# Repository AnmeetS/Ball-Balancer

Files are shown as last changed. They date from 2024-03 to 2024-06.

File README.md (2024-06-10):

<p align="center">project-image</p>

Hello and welcome to the GitHub repository of my Ball Balancing Robot! This project marks a significant milestone in my embdeded software engineering journey, combining my passion for robotics with hands-on learning and innovation. Below, I delve into the inspiration, process, challenges, and future plans for this project.

## Inspiration ✨

One of my most driving aspirations is to create a robot that can help people in their daily lives. This realization led me to discover my passion for robotics software development. Given the niche nature of this field and the lack of specific courses in school, I took it upon myself to explore the basics of robotics coding concepts over the past two months. This exploration began with working with PID algorithms, and it inspired me to create a ball balancing machine. The idea was to develop a project that could practically apply these concepts while also challenging my understanding and skills.

## The Process 🛠️

The project began with extensive research. I invested in stepper motors due to their high accuracy and quiet operation. The design needed a platform with at least two degrees of freedom (pitch and yaw) to angle the platform in any direction. Initially, I considered using a gimbal, but I encountered clearance issues with the motors. This led me to explore other manipulator designs, eventually settling on a 3-RPS parallel manipulator. A 3-RPS manipulator was ideal because it provided the necessary degrees of freedom, but I ultimately chose a varation of this manipulator (A 3-RRS manipulator platform) due to the lack of access to prismatic actuation.

Once the platform design was finalized, I attempted calculating the inverse kinematics necessary for coordinating platform tilt with stepper motor angles. This process involved advanced mathematical calculations, including solving complex equations related to the robot's geometry and movement using linear transformations. Each component—inverse kinematics values, resistive touchpad readings, motor control algorithms, and the PID control algorithm—was thoroughly tested. After a series of tests and refinements, I assembled and tuned the robot. The result is a finely tuned ball balancing machine, as demonstrated in the video below.

## Demo 🚀

[Watch the demo](https://www.anmeetsekhon.com/assets/videos/Ball%20Balancing%20Speed%20Up%20Video.mp4)

## Built with 💻

Technologies used in the project:

- Arduino
- C++
- Stepper Motors
- Solidworks

## Challenges I Ran Into 🚧

One of the biggest challenges was calculating the inverse kinematics. This complex calculation required a solid understanding of linear algebra and advanced mathematics. The process involved solving equations that define the relationship between the robot's physical structure and its movements. Specifically, it required deriving the mathematical model that translates the desired tilt of the platform into specific angles for the stepper motors. The complexity and precision required for these calculations pushed me to deepen my knowledge and skills in this area, making it one of the most challenging yet rewarding aspects of the project.

For those interested, a portion of the calculations performed for the inverse kinematics can be found [here](https://github.com/AnmeetS/Ball-Balancer/blob/main/Dynamic%20Plate%20Kinematics.pdf).

## What I Learned 📚

- Working with PID control algorithms
- Inverse kinematics calculations
- Stepper motor control and precision
- Integration of hardware and software components

## What's Next 🔮

- **Documentation:** More documentation highlighting how exactly everything is done and what steps I took.
- **Interactivity:** Developing a frontend interface to let users specify platform actions.

## Stay Connected 📢

Thank you for visiting my repository! Your feedback and contributions are always welcome. Let's make something amazing together!

---

**Note:** This project is a continuous work in progress, and some features may be added soon. Stay tuned!
**Inspiration:** This project was heavily inspired by existing ball balancing robots out there. While all the CAD and calculations I present are my own work, I drew significant inspiration from the two projects I have linked. All credits for this project go to [271828-](https://www.instructables.com/3DOF-Ball-on-Plate-Using-Closed-Loop-Stepper-Motor/) and [aaedmusa](https://www.instructables.com/Ball-Balancer/)

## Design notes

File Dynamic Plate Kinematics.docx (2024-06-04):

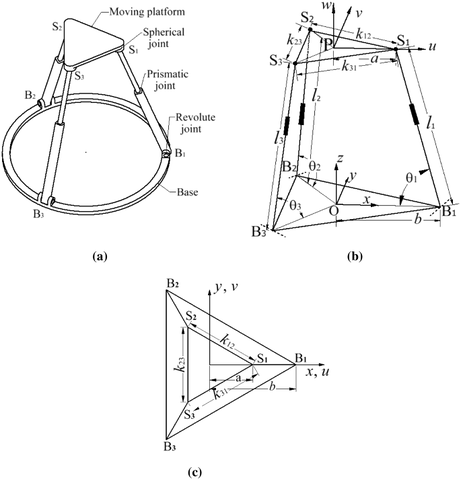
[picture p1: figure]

B_1 =[b00]

B_2 =R_Z (2/3π)∙B_1 =[cos(2/3π), -sin(2/3π), 0sin(2/3π), cos(2/3π), 00, 0, 1][b00]=[-1/2, -(√3)/2, 0(√3)/2, -1/2, 00, 0, 1][b00]=[-b/2(√3)/2b0]

B_3 =R_Z (4/3π)∙B_1 =[cos(4/3π), -sin(4/3π), 0sin(4/3π), cos(4/3π), 00, 0, 1][b00]=[-1/2, (√3)/2, 0-(√3)/2, -1/2, 00, 0, 1][b00]=[-b/2-(√3)/2b0]

S_1 = B_1 +L_1 =[b00]+R_Y (-θ_1 )[-l_1 00]=[b00]+[cos(-θ_1 ), 0, -sin(-θ_1 )0, 1, 0sin(-θ_1 ), 0, cos(-θ_1 )][-l_1 00]=[b00]+[-l_1 cos(-θ_1 )0-l_1 sin(-θ_1 )]=[b-l_1 cos(-θ_1 )0-l_1 sin(-θ_1 )]=[b-l_1 cos(θ_1 )0l_1 sin(θ_1 )]

S_2 = B_2 +L_2 =[-b/2(√3)/2b0]+R_Z (2/3π)R_Y (-θ_2 )[-l_2 00]=[-b/2(√3)/2b0]+[cos(2/3π), -sin(2/3π), 0sin(2/3π), cos(2/3π), 00, 0, 1][cos(-θ_2 ), 0, -sin(-θ_2 )0, 1, 0sin(-θ_2 ), 0, cos(-θ_2 )][-l_2 00]=[-b/2(√3)/2b0]+[-1/2, -(√3)/2, 0(√3)/2, -1/2, 00, 0, 1][-l_2 cos(-θ_2 )0-l_2 sin(-θ_2 )]=[-b/2(√3)/2b0]+[-1/2, -(√3)/2, 0(√3)/2, -1/2, 00, 0, 1][-l_2 cos(-θ_2 )0-l_2 sin(-θ_2 )]=[-b/2(√3)/2b0]+[1/2l_2 cos(-θ_2 )-(√3)/2l_2 cos(-θ_2 )-l_2 sin(-θ_2 )]=[-b/2+1/2l_2 cos(θ_2 )(√3)/2b-(√3)/2l_2 cos(θ_2 )l_2 sin(θ_2 )]

S_3 = B_3 +L_3 =[-b/2-(√3)/2b0]+R_Z (4/3π)R_Y (-θ_3 )[-l_3 00]=[-b/2-(√3)/2b0]+[cos(4/3π), -sin(4/3π), 0sin(4/3π), cos(4/3π), 00, 0, 1][cos(-θ_3 ), 0, -sin(-θ_3 )0, 1, 0sin(-θ_3 ), 0, cos(-θ_3 )][-l_3 00]=[-b/2-(√3)/2b0]+[-1/2, (√3)/2, 0-(√3)/2, -1/2, 00, 0, 1][-l_3 cos(-θ_3 )0-l_3 sin(-θ_3 )]=[-b/2-(√3)/2b0]+[-1/2, (√3)/2, 0-(√3)/2, -1/2, 00, 0, 1][-l_3 cos(-θ_3 )0-l_3 sin(-θ_3 )]=[-b/2-(√3)/2b0]+[1/2l_3 cos(-θ_3 )(√3)/2l_3 cos(-θ_3 )l_3 sin(θ_3 )]=[-b/2+1/2l_3 cos(θ_3 )-(√3)/2b+(√3)/2l_3 cos(θ_3 )l_3 sin(θ_3 )]

K_(S1,S2) = S_2 -S_1 =[-b/2+1/2l_2 cos(θ_2 )(√3)/2b-(√3)/2l_2 cos(θ_2 )l_2 sin(θ_2 )]-[b-l_1 cos(θ_1 )0l_1 sin(θ_1 )]=[-b/2+1/2l_2 cos(θ_2 )-b+l_1 cos(θ_1 )(√3)/2b-(√3)/2l_2 cos(θ_2 )l_2 sin(θ_2 )-l_1 sin(θ_1 )]=[-(3b)/2+1/2l_2 cos(θ_2 )+l_1 cos(θ_1 )(√3)/2b-(√3)/2l_2 cos(θ_2 )l_2 sin(θ_2 )-l_1 sin(θ_1 )]

K_(S2,S3) = S_3 -S_2 =[-b/2+1/2l_3 cos(θ_3 )-(√3)/2b+(√3)/2l_3 cos(θ_3 )l_3 sin(θ_3 )]-[-b/2+1/2l_2 cos(θ_2 )(√3)/2b-(√3)/2l_2 cos(θ_2 )l_2 sin(θ_2 )]=[-b/2+1/2l_3 cos(θ_3 )+b/2-1/2l_2 cos(θ_2 )-(√3)/2b+(√3)/2l_3 cos(θ_3 )-(√3)/2b+(√3)/2l_2 cos(θ_2 )l_3 sin(θ_3 )-l_2 sin(θ_2 )]=[1/2l_3 cos(θ_3 )-1/2l_2 cos(θ_2 )-√3b+(√3)/2l_3 cos(θ_3 )+(√3)/2l_2 cos(θ_2 )l_3 sin(θ_3 )-l_2 sin(θ_2 )]

K_(S3,S1) = S_1 -S_3 =[b-l_1 cos(θ_1 )0l_1 sin(θ_1 )]-[-b/2+1/2l_3 cos(θ_3 )-(√3)/2b+(√3)/2l_3 cos(θ_3 )l_3 sin(θ_3 )]=[b-l_1 cos(θ_1 )+b/2-1/2l_3 cos(θ_3 )(√3)/2b-(√3)/2l_3 cos(θ_3 )l_1 sin(θ_1 )-l_3 sin(θ_3 )]=[(3b)/2-l_1 cos(θ_1 )-1/2l_3 cos(θ_3 )(√3)/2b-(√3)/2l_3 cos(θ_3 )l_1 sin(θ_1 )-l_3 sin(θ_3 )]

|K_(S1,S2) |^2 =k_12^2 =K_(S1,S2) ^T K_(S1,S2) =[-(3b)/2+1/2l_2 cos(θ_2 )+l_1 cos(θ_1 ), (√3)/2b-(√3)/2l_2 cos(θ_2 ), l_2 sin(θ_2 )-l_1 sin(θ_1 )][-(3b)/2+1/2l_2 cos(θ_2 )+l_1 cos(θ_1 )(√3)/2b-(√3)/2l_2 cos(θ_2 )l_2 sin(θ_2 )-l_1 sin(θ_1 )]=(-(3b)/2+1/2l_2 cos(θ_2 )+l_1 cos(θ_1 ))^2 +((√3)/2b-(√3)/2l_2 cos(θ_2 ))^2 +(l_2 sin(θ_2 )-l_1 sin(θ_1 ))^2 =((3b)/2)^2 -2(3b)/2(1/2l_2 cos(θ_2 ))-2(3b)/2l_1 cos(θ_1 )+(1/2l_2 cos(θ_2 ))^2 +21/2l_2 cos(θ_2 )l_1 cos(θ_1 )+(l_1 cos(θ_1 ))^2 +((√3)/2b)^2 -2((√3)/2b)((√3)/2l_2 cos(θ_2 ))+((√3)/2l_2 cos(θ_2 ))^2 +(l_2 sin(θ_2 ))^2 -2(l_2 sin(θ_2 ))(l_1 sin(θ_1 ))+(l_1 sin(θ_1 ))^2 =(9b^2)/4-(3b)/2(l_2 cos(θ_2 ))-3bl_1 cos(θ_1 )+1/4l_2 ^2 cos(θ_2 )^2 +l_2 cos(θ_2 )l_1 cos(θ_1 )+l_1 ^2 cos(θ_1 )^2 +3/4b^2 -(3/2b)(l_2 cos(θ_2 ))+3/4l_2 ^2 cos(θ_2 )^2 +l_2 ^2 sin(θ_2 )^2 -2(l_2 sin(θ_2 ))(l_1 sin(θ_1 ))+l_1 ^2 sin(θ_1 )^2 ==3b^2 -(3b)/2(l_2 cos(θ_2 ))-3bl_1 cos(θ_1 )+l_2 ^2 (1/4cos(θ_2 )^2 +sin(θ_2 )^2 +3/4cos(θ_2 )^2 )+l_2 cos(θ_2 )l_1 cos(θ_1 )+l_1 ^2 (cos(θ_1 )^2 +sin(θ_1 )^2 )-(3/2b)(l_2 cos(θ_2 ))-2(l_2 sin(θ_2 ))(l_1 sin(θ_1 ))=3b^2 -3bl_2 cos(θ_2 )-3bl_1 cos(θ_1 )+l_2 ^2 +l_1 l_2 cos(θ_2 )cos(θ_1 )+l_1 ^2 -2l_1 l_2 sin(θ_2 )sin(θ_1 )

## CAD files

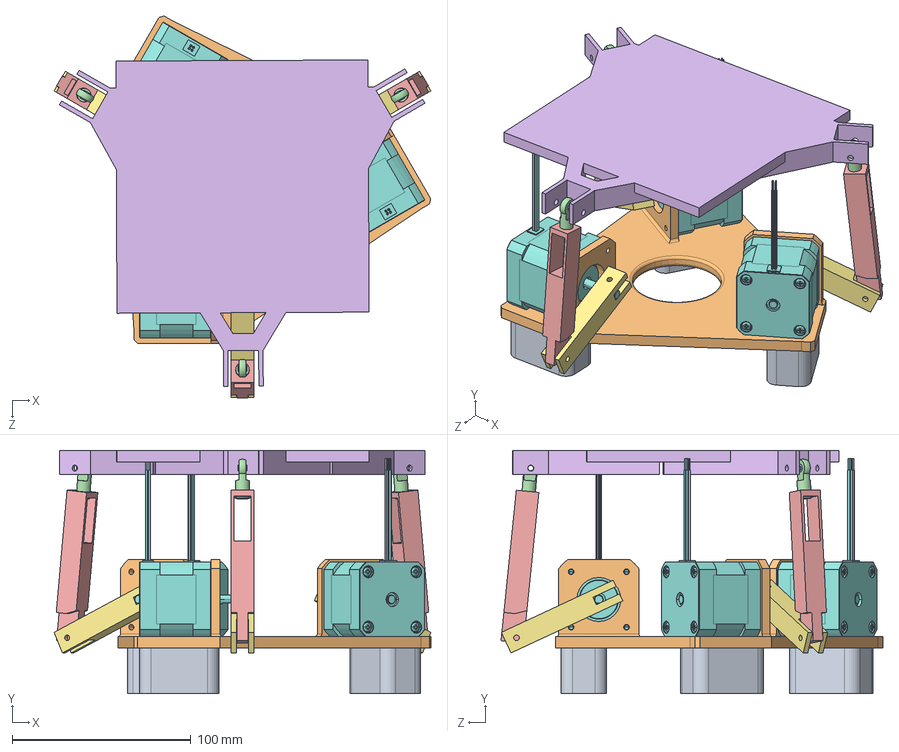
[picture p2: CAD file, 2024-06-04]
design/motor/Ball Balancing Robot.SLDASM
210.7 x 135.9 x 213.6 mm
17Y202S-LW4 x 3
BB Link 1 x 3
BB Platform
BB Link 2 x 3
tierod - Part 1 x 3
tierod_ball - Part 1 x 3
BB Base
BB Base Feet x 3

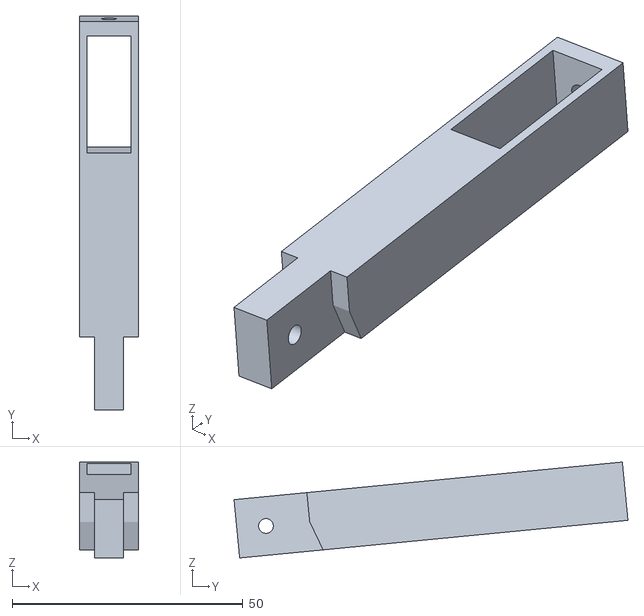
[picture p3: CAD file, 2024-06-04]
design/BB Link 2.STL
12.7 x 85.4 x 20.8

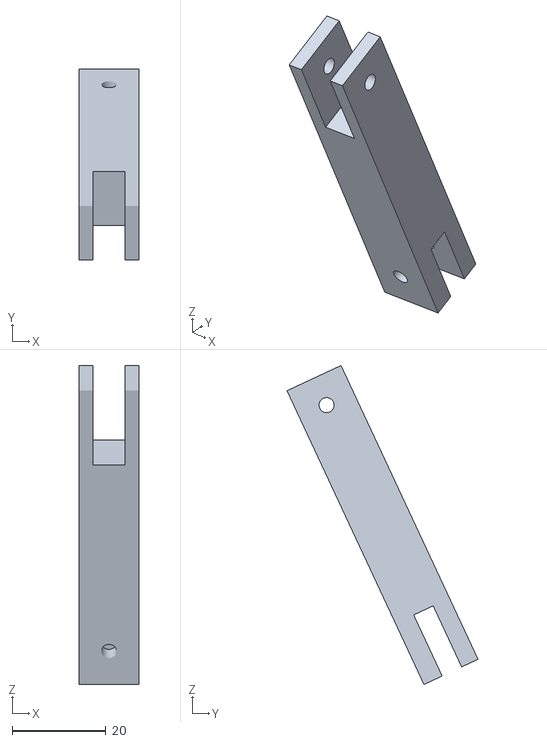
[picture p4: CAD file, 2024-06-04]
design/BB Link 1.STL
12.7 x 40.7 x 67.9

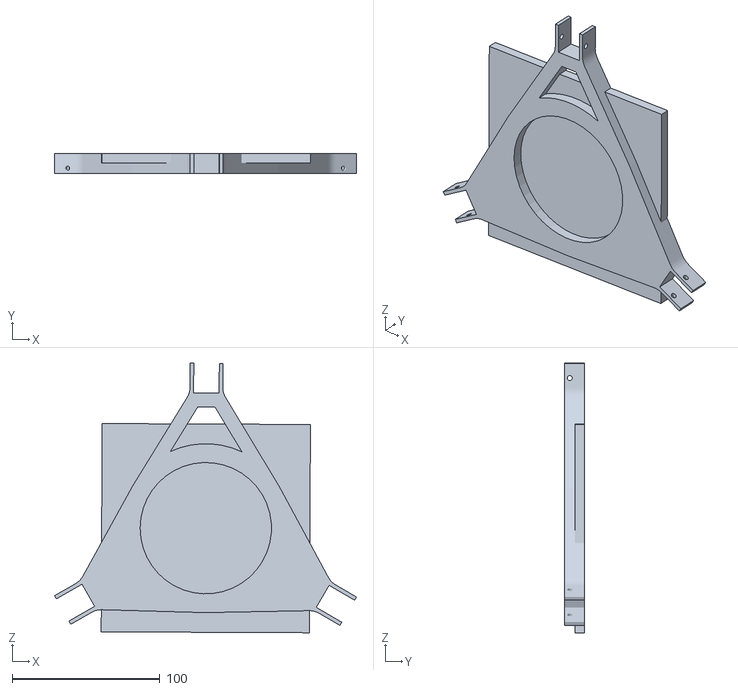
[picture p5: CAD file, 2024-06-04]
design/BB Platform.STL
204.4 x 13.3 x 182.5

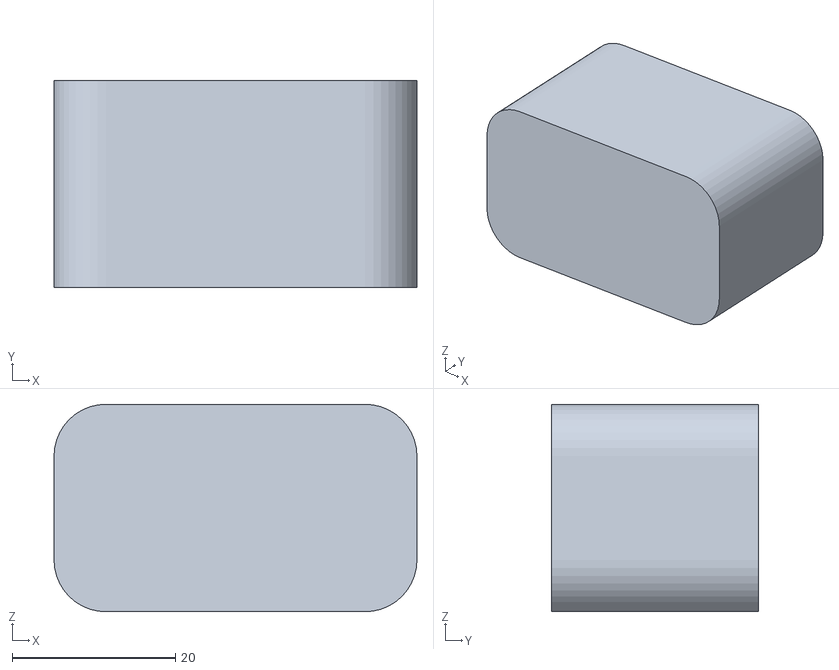
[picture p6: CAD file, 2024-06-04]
design/BB Base Feet.STL
44.4 x 25.4 x 25.4

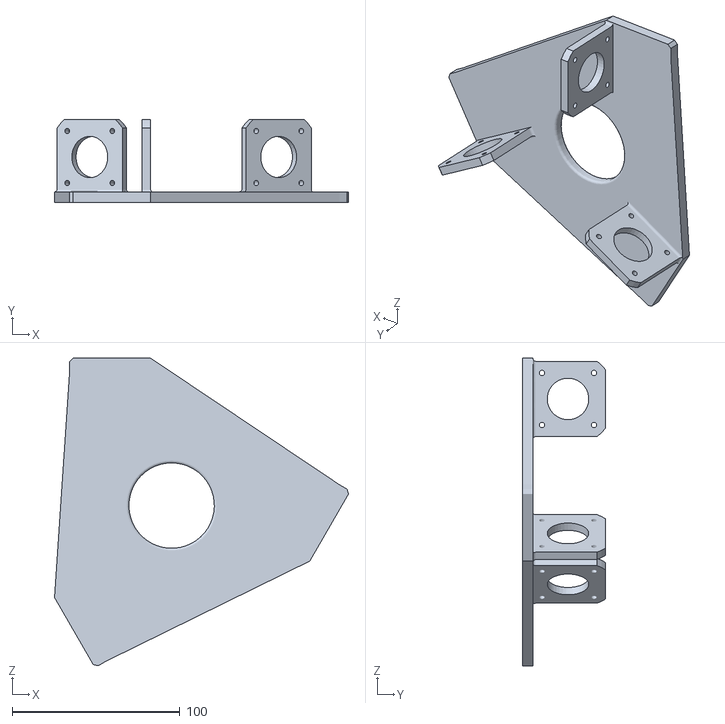
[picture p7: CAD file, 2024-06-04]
design/BB Base.STL
175.0 x 49.6 x 183.2

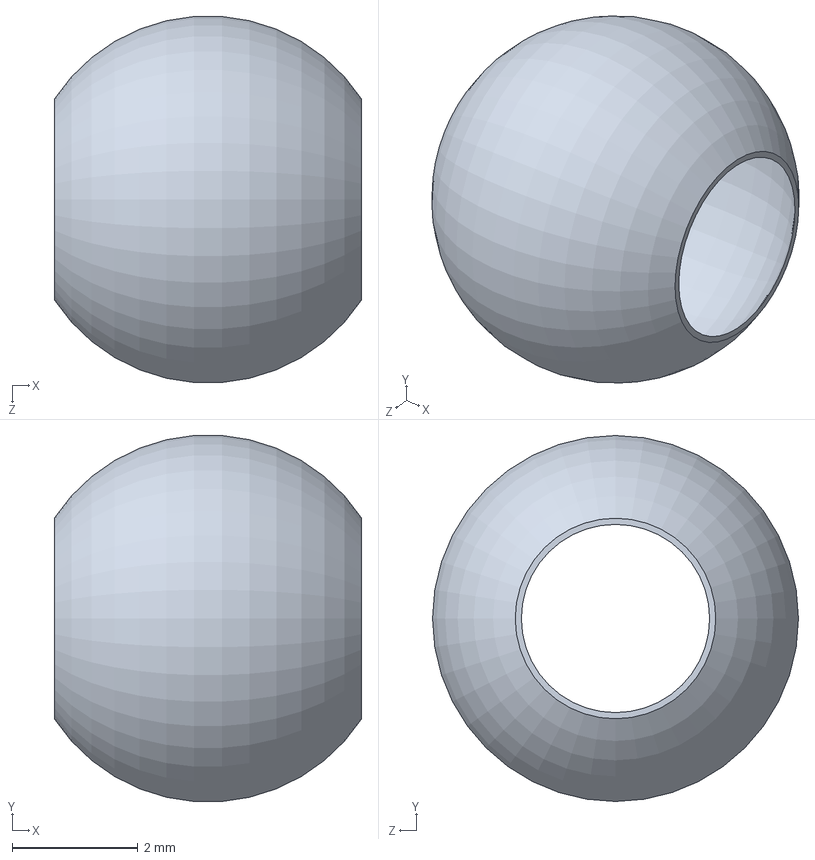
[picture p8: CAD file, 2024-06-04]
design/motor/tierod_ball - Part 1.sldprt
4.90 x 5.83 x 5.83 mm

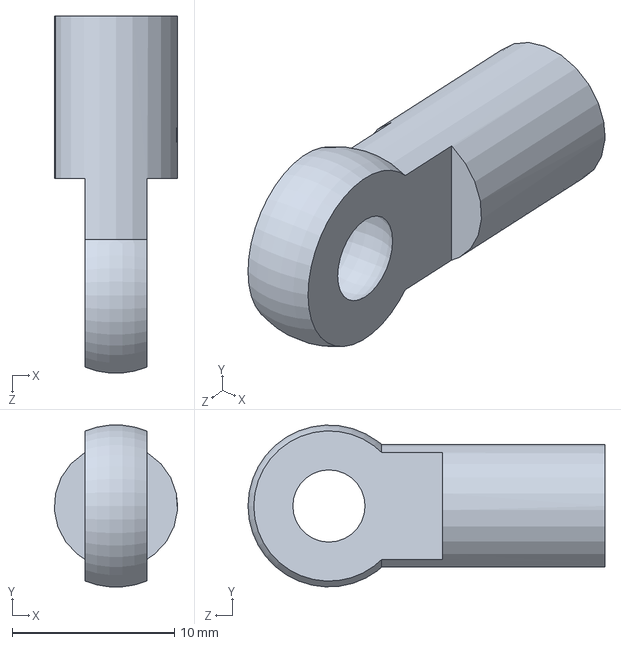
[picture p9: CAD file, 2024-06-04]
design/motor/tierod - Part 1.sldprt
7.59 x 9.96 x 22.0 mm

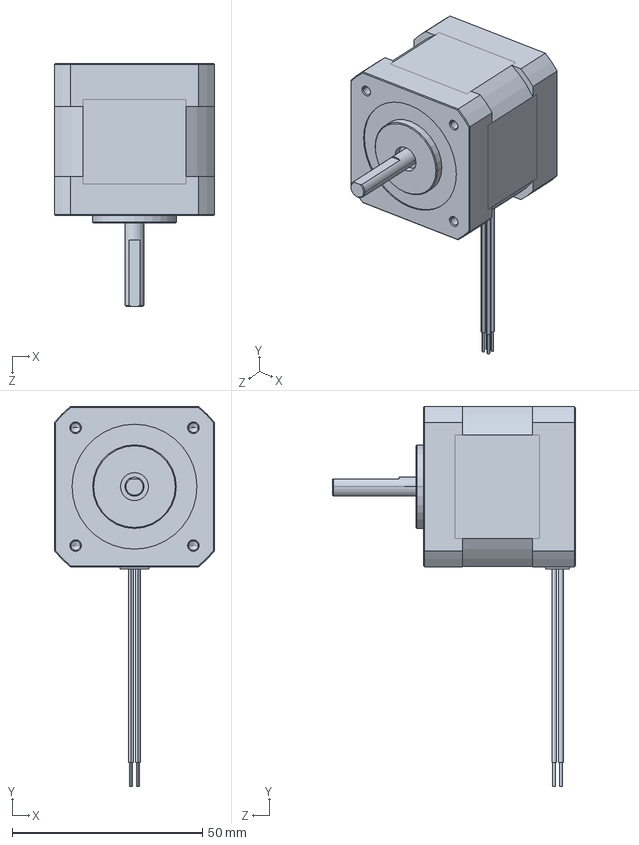
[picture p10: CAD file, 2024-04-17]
design/motor/17Y202S-LW4.SLDPRT
42.2 x 99.9 x 63.9 mm

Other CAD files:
design/motor/Ball Balancer Master Model Creator.SLDPRT
design/motor/BB Link 2.SLDPRT
design/motor/BB Base Feet.SLDPRT
design/motor/BB Base.SLDPRT
design/motor/Ball Balancer Master Model.SLDPRT
design/motor/BB Link 1.SLDPRT
design/motor/BB Platform.SLDPRT

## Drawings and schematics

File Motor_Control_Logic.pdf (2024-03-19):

Motor Control Logic | a

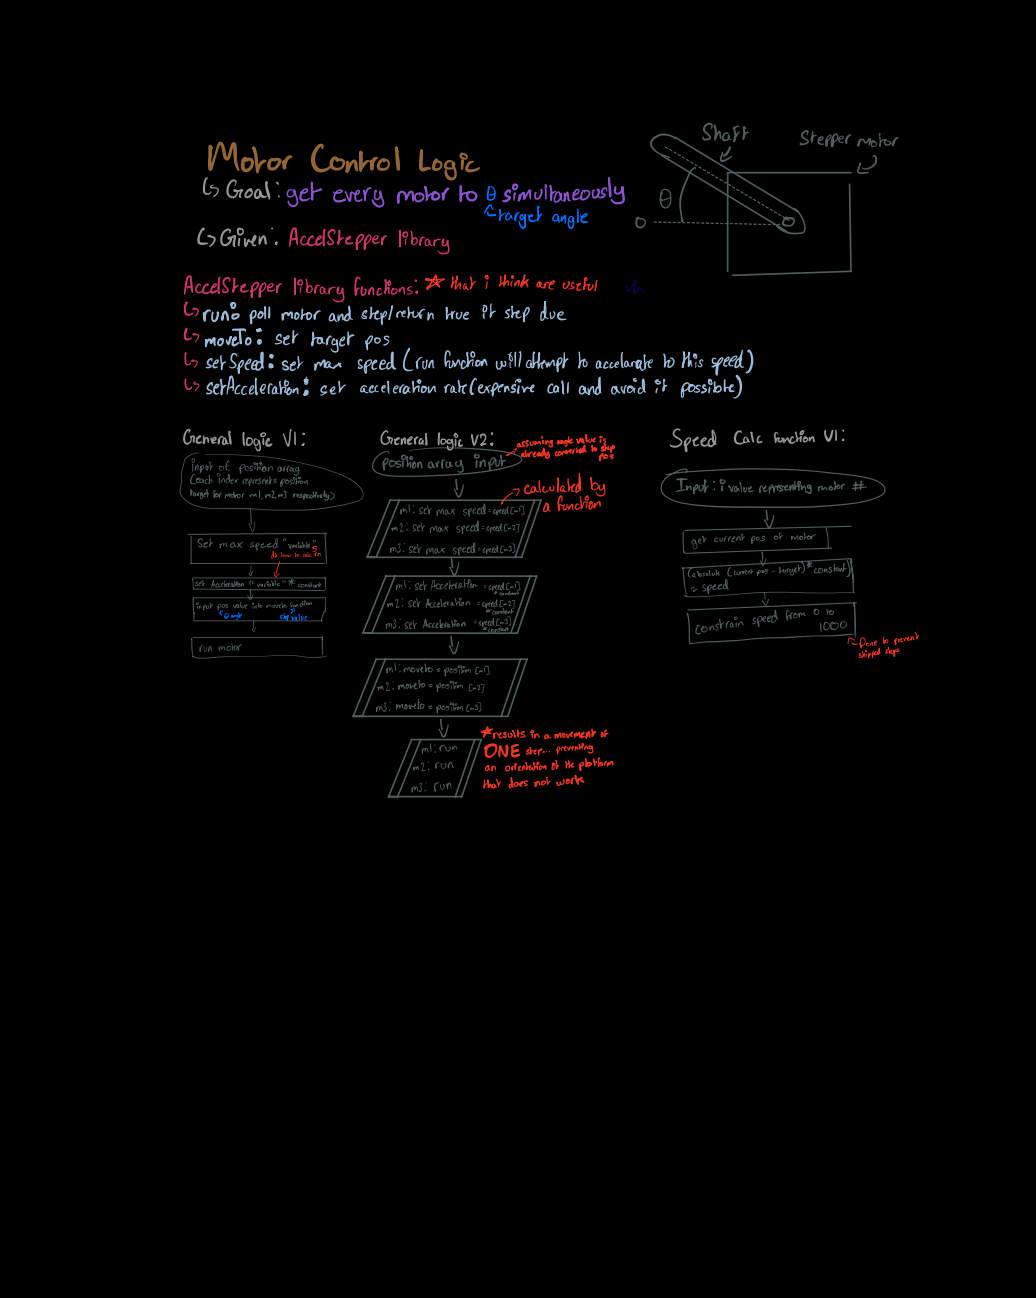
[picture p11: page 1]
Shaft; steppermotor; Crargetangle; of Given Accelstepperlibrary; Accelstepper libraryfunctions; thati thinkareuseful; General logic V1; GenerallogicV2; positionarrayinp.fi; speedcalcfunction v1; Inputiivaluerepresentingmobr setmaxspeed; em.li speak; calculatedby a function; m2setmaxspeedspeedma; setmax peek; mssetmaxspeedspeedmy; getcurrentp ofmotor; HerAcceleration; variable; constant; mlset; ethration; espeed; mnt; tinpot; move; m2setAcceleration speedema; mssetAcceleration is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

Goal get every motor to simultaneously

run pollmotorandstepreturntrue it stepdue
moveto set targetpos
setspeed set max speed runfunctionwillattempttoaccelerate tothisspeed
setacceleration set accelerationrateexpensive callandavoid it possible

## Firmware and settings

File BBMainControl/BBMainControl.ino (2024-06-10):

//Libraries
#include <AccelStepper.h>
#include <MultiStepper.h>
#include <math.h>
#include <TouchScreen.h>
#include <BBInverseKinematics.h>

//Step Constants
#define oneStep 2
#define twoStep 3
#define threeStep 4

//Direction Constants
#define oneDir 5
#define twoDir 6
#define threeDir 7

//Stepper Motor Objects
AccelStepper stepper1(1, oneStep, oneDir);
AccelStepper stepper2(1, twoStep, twoDir);
AccelStepper stepper3(1, threeStep, threeDir);
MultiStepper steppers;

//Motor Variables
long tarAng[3] = { 180, 180, 180};
long tarPos[3] = { 0, 0, 0};
double speed[3] = { 0, 0, 0}, speedPrev[3], ks = 25, ka = 50; 
long curPos[3] = { 0, 0, 0};
double origPos[3] = {0, 0, 0};
double origAng = 205;

//Touch Screen Object
TouchScreen ts = TouchScreen(A1, A0, A3, A2, 0 );

//Touch screen center variables
double Xoffset = 500; 
double Yoffset = 500;  

//Inverse Kinematics Object
Robot robot(2.5, 4, 2, 3.75);

//PID variables
double error[2] = { 0, 0 }, errorPrev[2], integr[2] = { 0, 0 }, deriv[2] = { 0, 0 }, out[2];   
double xval,yval; //ball x and y position
double kp = 3E-4, ki = 0.75E-6, kd = 7.5E-3;
long timeI;  

//Other Variables
double angToStep = 17.78;
bool detected = 0; 
//bool initTap = 0; 
bool centered = false;
bool triangle[3] = {false, false, false};
bool rectangle[4] = {false, false, false, false};
long startTime = millis();

void setup() {
  Serial.begin(115200);
  motorSetup();
  delay(2000);
  
}

void motorSetup(){
  steppers.addStepper(stepper1);
  steppers.addStepper(stepper2);
  steppers.addStepper(stepper3);

  for (int i = 0; i < 3; i++){
    origPos[i]=origAng*angToStep;
    tarPos[i]  = tarAng[i] * angToStep;
  }

  stepper1.setCurrentPosition(origPos[0]);
  stepper2.setCurrentPosition(origPos[1]);
  stepper3.setCurrentPosition(origPos[2]);

  stepper1.setMaxSpeed(speed[0]);
  stepper2.setMaxSpeed(speed[1]);
  stepper3.setMaxSpeed(speed[2]);
}

void loop() {
  
  centerBalance();
  trianglePattern();
  centerBalance();
  rectanglePattern();
  Serial.println("Main Loop");
}

void PID (double xVal, double yVal, double tarX, double tarY){
  for (int i = 0; i < 2; i++) {
      errorPrev[i] = error[i];                                                                    
      error[i] = (i == 0) * (Xoffset - xVal - tarX) + (i == 1) * (Yoffset - yVal - tarY);
      integr[i] += error[i] + errorPrev[i];                                                        
      deriv[i] = error[i] - errorPrev[i];                                                          
      deriv[i] = isnan(deriv[i]) || isinf(deriv[i]) ? 0 : deriv[i];                               
      out[i] = kp * error[i] + ki * integr[i] + kd * deriv[i];                                     
      out[i] = constrain(out[i], -0.25, 0.25);                                                     
    }
}

void moveTo(double hz, double nx, double ny){
  if (detected) {
    for (int i=0; i<3;i++){
    }
  }
  else{
    for (int i=0; i<3;i++){
      tarAng[i]= robot.angle(i, hz, 0, 0);
      tarPos[i]  = tarAng[i] * angToStep;
    }
  }

  for (int i = 0; i < 3; i++) {
      speedPrev[i] = speed[i];
      curPos[i] = (i == 0) * stepper1.currentPosition() + (i == 1) * stepper2.currentPosition() + (i == 2) * stepper3.currentPosition();
      speed[i] = abs(curPos[i] - tarPos[i]) * ks;
      speed[i] = constrain(speed[i], speedPrev[i] - 200, speedPrev[i] + 200);
      speed[i] = constrain(speed[i], 0, 1000);
    }
  stepper1.setMaxSpeed(speed[0]);
  stepper2.setMaxSpeed(speed[1]);
  stepper3.setMaxSpeed(speed[2]);
  
  stepper1.setAcceleration(speed[0]*ka);
  stepper2.setAcceleration(speed[1]*ka);
  stepper3.setAcceleration(speed[2]*ka);
 
  stepper1.moveTo(tarPos[0]);
  stepper2.moveTo(tarPos[1]);
  stepper3.moveTo(tarPos[2]);
  
  stepper1.run();
  stepper2.run();
  stepper3.run();  
}

void balance(double hz, double xtar, double ytar){
  TSPoint p = ts.getPoint();  
  if (p.x != 0) {
    detected = 1;
    PID(p.x, p.y, xtar, ytar);
    for (int i = 0; i < 3; i++) {
      tarAng[i] = robot.angle(i, hz, out[0], out[1]); 
      tarPos[i] = tarAng[i] * angToStep; 
    }
  } else {
    delay(10);                  
    TSPoint p = ts.getPoint();  
    if (p.x == 0) {    
      detected = 0;
      for (int i = 0; i < 3; i++) {
        tarAng[i] = robot.angle(i, hz, 0, 0);
        tarPos[i] = tarAng[i] * angToStep;
      }
    }
  }

  timeI = millis();
  while ((millis() - timeI < 20)) {
    moveTo(hz, out[0], out[1]);  
  }
}

bool balanceToTarget(double xtar, double ytar, long waitTime, double kb) {
  double bound = 25*kb;
  balance(4.25, xtar, ytar);
  if (detected) {
    if ((error[0] > -bound && error[0] < bound) && (error[1] > -bound && error[1] < bound)) {
      if (millis() - startTime >= waitTime) {
        return true;
      }
    } else {
      startTime = millis();
    }
  } else {
    startTime = millis();
  }
  return false;
}

void centerBalance(){
  centered = false;
  startTime = millis();
  while (!centered){
    centered=balanceToTarget(0, 0, 2000, 1.5);
    Serial.println("Center Loop");
  }
}

void trianglePattern(){
  for (int i = 0; i < 2; i++){
    triangle [0] = false;
    startTime = millis();
    while (!triangle[0]){
      triangle[0] = balanceToTarget(0, 250, 1500, 2);
      Serial.println("Tri1 Loop");
    }
    triangle [1] = false;
    startTime = millis();
    while (!triangle[1]){
      triangle[1] = balanceToTarget(-216.5, -125, 1500, 2);
      Serial.println("Tri2 Loop");
    }
    triangle [2] = false;
    startTime = millis();
    while (!triangle[2]){
      triangle[2] = balanceToTarget(216.5, -125, 1500, 2);
      Serial.println("Tri3 Loop");
    }
  }
}

void rectanglePattern(){
  for (int i = 0; i < 3; i++){
    rectangle [0] = false;
    startTime = millis();
    while (!rectangle[0]){
      rectangle[0] = balanceToTarget(-250, 200, 1500, 2);
      Serial.println("Rect1 Loop");
    }
    rectangle [1] = false;
    startTime = millis();
    while (!rectangle[1]){
      rectangle[1] = balanceToTarget(-250, -200, 1500, 2);
      Serial.println("Rect2 Loop");
    }
    rectangle [2] = false;
    startTime = millis();
    while (!rectangle[2]){
      rectangle[2] = balanceToTarget(250, -200, 1500, 2);
      Serial.println("Rect3 Loop");
    }
    rectangle [3] = false;
    startTime = millis();
    while (!rectangle[3]){
      rectangle[3] = balanceToTarget(250, 200, 1500, 2);
      Serial.println("Rect4 Loop");
    }
  }
}

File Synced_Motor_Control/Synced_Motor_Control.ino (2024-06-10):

//Libraries
#include <AccelStepper.h>
#include <MultiStepper.h>
#include <math.h>

//Step Constants
#define oneStep 2
#define twoStep 3
#define threeStep 4

//Direction Constants
#define oneDir 5
#define twoDir 6
#define threeDir 7

//Setting up the classes
AccelStepper stepper1(1, oneStep, oneDir);
AccelStepper stepper2(1, twoStep, twoDir);
AccelStepper stepper3(1, threeStep, threeDir);
MultiStepper steppers;

double angToStep = 17.78;
long tarAngle[3]={ 90, 90, 90 };
long posTar[3]={ 0, 0, 0};
double speed[3] = { 0, 0, 0 }, speedPrev[3], ks = 10; 
long posCur[3]={ 0,0,0 };
long posOrig[3]={0, 0, 0};

void setup() {
  Serial.begin(115200);
  steppers.addStepper(stepper1);
  steppers.addStepper(stepper2);
  steppers.addStepper(stepper3);

  for (int i = 0; i < 3; i++){
    posOrig[i]=posOrig[i]*angToStep;
  }

  stepper1.setCurrentPosition(posOrig[0]);
  stepper2.setCurrentPosition(posOrig[1]);
  stepper3.setCurrentPosition(posOrig[2]);
  
  Serial.println((String) "pos1 "+stepper1.currentPosition()+ " pos2 "+stepper2.currentPosition() + " pos3 "+ stepper3.currentPosition());

  delay(5000);

  stepper1.setMaxSpeed(speed[0]);
  stepper2.setMaxSpeed(speed[1]);
  stepper3.setMaxSpeed(speed[2]);

}

void loop() {
  moveTo(); 
}

void moveTo(){
  stepper1.setMaxSpeed(speed[0]);
  stepper2.setMaxSpeed(speed[1]);
  stepper3.setMaxSpeed(speed[2]);
  stepper1.setAcceleration(speed[0]*50);
  stepper2.setAcceleration(speed[1]*50);
  stepper3.setAcceleration(speed[2]*50);
  stepper1.moveTo(posTar[0]);
  stepper2.moveTo(posTar[1]);
  stepper3.moveTo(posTar[2]);
  Serial.println((String) "speed 1 "+ stepper1.speed());
  stepper1.run();
  stepper2.run();
  stepper3.run();
}

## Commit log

2024-03-19 Motor Control
    Created a pdf describing logic as well as a code snippet for synced control of motors.
    Next goal: Read XY coordinates from touchpad and map to motor angles
2024-04-20 model update
    [BB Base.SLDPRT, BB Link 1.SLDPRT, BB Link 2.SLDPRT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]
2024-04-21 final version working
    [BB Base.SLDPRT, BB Link 1.SLDPRT, BB Link 2.SLDPRT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]
2024-06-04 latest changes
    [BB Base Feet.SLDPRT, BB Base Feet.STL, BB Base.SLDPRT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]
2024-06-04 added kinematics documentation
2024-06-04 kinematics documentation
